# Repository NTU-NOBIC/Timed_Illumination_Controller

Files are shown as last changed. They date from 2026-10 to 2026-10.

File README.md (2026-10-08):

# Timed Illumination Controller

Firmware for an **Arduino Teensy 4.0** that coordinates two LED-control outputs with camera acquisition. In timed acquisition, the Teensy generates an external camera trigger and monitors the camera's trigger-ready feedback. A second mode uses camera feedback to control LED illumination during externally controlled continuous streaming.

## Features

- **Timed acquisition:** programmable camera trigger intervals (`t1`–`t4`) and LED lead/lag intervals (`t5`–`t8`).
- **Streaming mode:** LED control based on the camera feedback input and configurable `ts` interval.
- **Two active-HIGH channels:** Channel A and Channel B, with firmware-enforced mutual exclusion.
- **Camera monitoring:** frame-event counting from the camera feedback signal (mode-dependent validation).
- **Serial interface:** status, timing, acquisition, streaming, manual LED control, and configuration commands at **115200 baud**.
- **EEPROM presets:** save/load timing, cycle count, and selected channel in slots **0–10**; slot **0** is read at startup.

## Firmware and connections

Main sketch: [`Timed_Cam_Trig_LED_Control.ino`](Timed_Cam_Trig_LED_Control.ino)

| Teensy 4.0 pin | Firmware name | Direction | Purpose |
|---|---|---|---|
| 9 | `CAM_TRIG_OUT` | Output | Active-HIGH camera external trigger |
| 10 | `CAM_TRIG_READY` | Input (`INPUT_PULLUP`) | Camera feedback |
| 13 (`LED_BUILTIN`) | `GATE_A` | Output | Active-HIGH Channel A gate (also onboard LED) |
| 14 | `GATE_B` | Output | Active-HIGH Channel B gate |

**Important:** Confirm interface voltage levels, signal polarity, camera feedback configuration, and external LED driver requirements before connecting hardware. The sketch's naming of its camera and signals does not establish compatibility with every camera configuration.
Note: Teensy 4.0 GPIO input and output logic voltage is 3.3V.

## Quick start

1. Open `Timed_Cam_Trig_LED_Control.ino` in an Arduino environment configured for **Teensy 4.0**.
2. Compile and upload the sketch to the board.
3. Open a serial terminal at **115200 baud** and send commands terminated by a newline.
4. Send `help` to display the implemented commands or `?` to view status and timing settings.
5. For timed acquisition, configure the camera for the expected external-trigger/ready-signal operation, then issue `r`. Enter `q` followed by Enter to abort the timed run.
6. For streaming mode, ensure the camera feedback input is configured for the exposure signal expected by the firmware, then issue `stm on`; use `stm off` to disable the mode.

See [**USER_GUIDE.md**](./firmware/USER_GUIDE.md) under firmware folder for full commands, parameter definitions, default values, operating procedures, and EEPROM details.

## Documentation scope

This README describes functionality present in the supplied `.ino` sketch. Channel names A/B are firmware labels; the sketch does **not** assign LED colours or fluorescence filter bands. Camera operation and image saving must be verified separately on the actual system.

## Disclaimer and licensing

The firmware is provided without any assurance of suitability or safe operation with a particular hardware configuration. Review and test signal timing and electrical interfaces before use.

**License:** No license grant has been inferred from the `.ino` source. Add an appropriate `LICENSE` file only after confirming the intended licensing terms with the code's rights holders.

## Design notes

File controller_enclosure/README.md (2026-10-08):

# Controller Enclosure — 3D CAD Model

This folder contains a 3D CAD model for the enclosure associated with the **Timed Illumination Controller** project.

## File

| File | Description |
| --- | --- |
| [`Illum_driver_enclosure_v1b.step`](./Illum_driver_enclosure_v1b.step) | Controller enclosure geometry in STEP format (version `v1b`). |

## Viewing and Using the Model

1. Download `Illum_driver_enclosure_v1b.step`.
2. Open or import it in a CAD application that supports STEP files (for example, FreeCAD, Autodesk Fusion, or SOLIDWORKS).
3. Inspect the geometry, dimensions, clearances, and fit against your hardware before manufacturing.
4. If required, export the model to a manufacturing format such as STL for 3D-printing preparation.

## File Information

- **Format:** STEP (`.step`), a neutral 3D CAD exchange format.
- **STEP schema:** AP214 (`AUTOMOTIVE_DESIGN`).
- **Model geometry:** The uploaded file contains two named solid bodies, `Body1` and `Body3`.
- **Version:** `v1b` (from the filename).

> **Note:** Material, print orientation, manufacturing tolerances, hardware compatibility, and assembly instructions are not specified in the STEP file. Verify these before fabrication.

## Related Project Files

See the [main project README](../README.md) for an overview of the Timed Illumination Controller.

## Disclaimer

The CAD model is provided **AS IS**, without a guarantee of fitness for a particular application. Check dimensions, electrical clearances, and mechanical fit before fabrication or use.

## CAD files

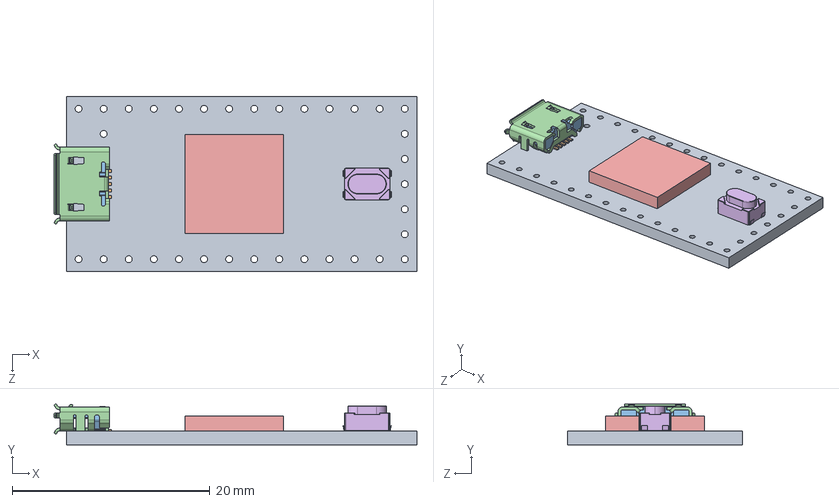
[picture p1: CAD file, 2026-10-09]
PCB/3d/Teensy_4.0_Assembly.STEP
36.8 x 4.12 x 17.7 mm
Teensy_4.0_PCB
Micro USB-B Female 5Pin SMD
NXP iMXRT1062
SKRPACE010 v4

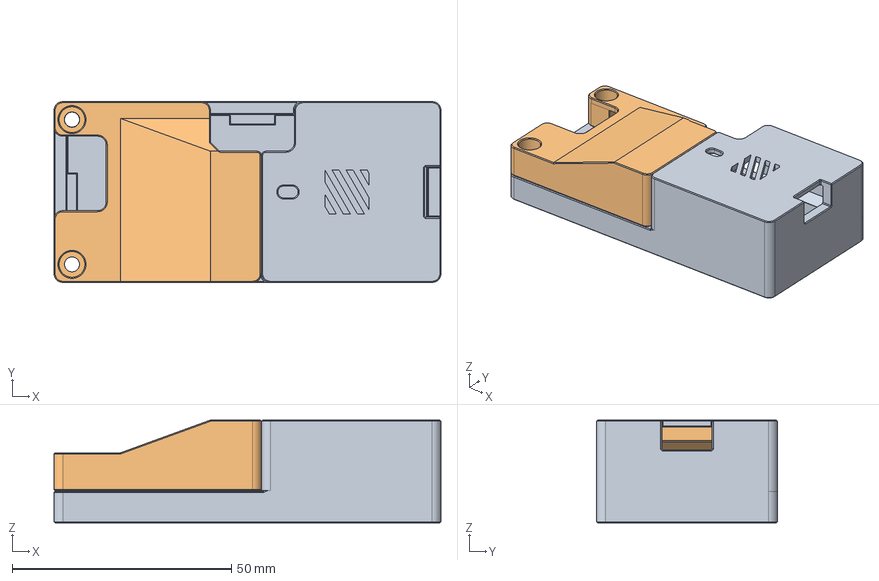
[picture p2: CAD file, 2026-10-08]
controller_enclosure/Illum_driver_enclosure_v1b.step
88.2 x 41.2 x 23.4 mm

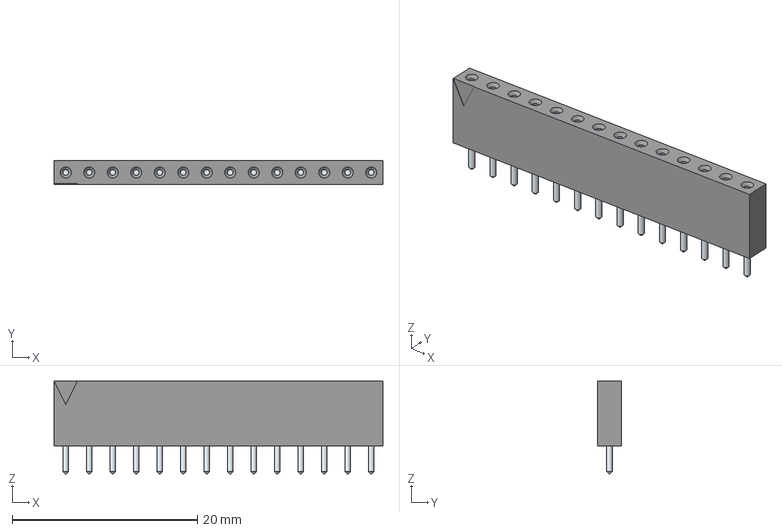
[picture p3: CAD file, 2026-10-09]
PCB/3d/801-87-014-10-001101.stp
35.6 x 2.54 x 10.0 mm
LeadsArray

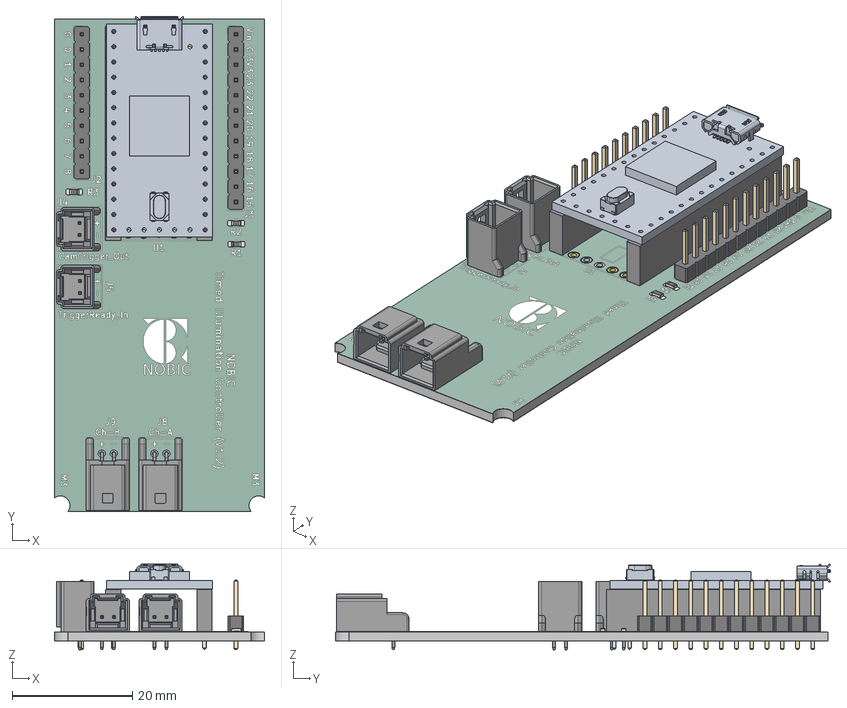
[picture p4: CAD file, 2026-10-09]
PCB/3d/IlluminationDriver_v1p2.step
35.0 x 82.4 x 14.3 mm
R_0603_1608Metric x 3
DF51KB-2P-2DS x 2
PinHeader_1x10_P2.54mm_Vertical
DF51K-2P-2DSA x 2
LeadsArray x 2
Teensy_4.0_PCB
Micro USB-B Female 5Pin SMD
NXP iMXRT1062
SKRPACE010 v4
PinHeader_1x12_P2.54mm_Vertical
IlluminationDriver_copper
IlluminationDriver_pad
IlluminationDriver_via
IlluminationDriver_silkscreen
IlluminationDriver_soldermask
IlluminationDriver_PCB

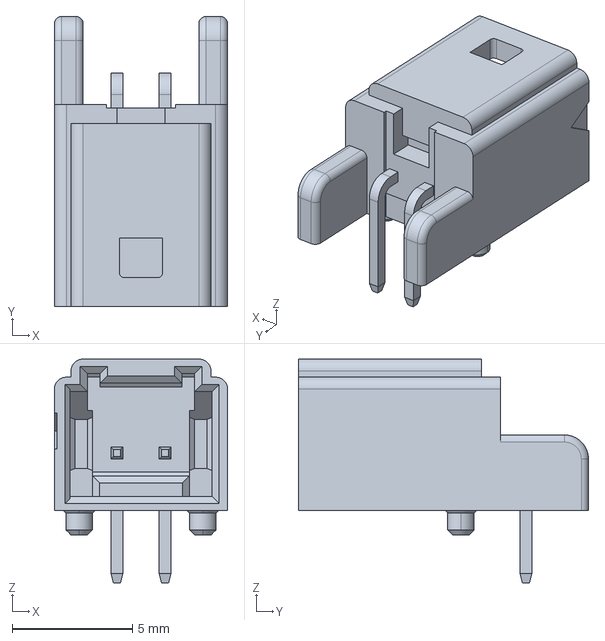
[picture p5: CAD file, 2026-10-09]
PCB/3d/DF51KB-2P-2DS(800).stp
7.20 x 12.0 x 9.30 mm

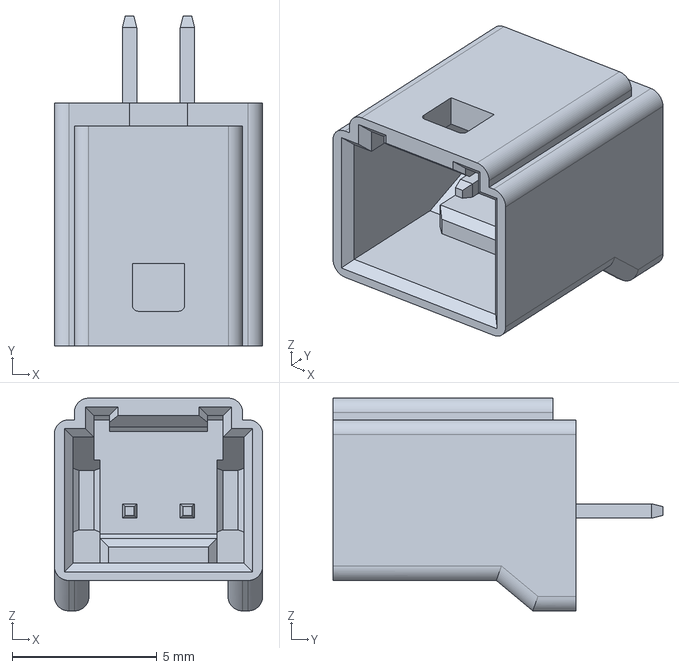
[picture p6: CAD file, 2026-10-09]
PCB/3d/DF51K-2P-2DSA(800).stp
7.20 x 11.4 x 7.35 mm

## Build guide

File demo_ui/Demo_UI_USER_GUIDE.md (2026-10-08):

# Demo UI User Guide

This guide explains how to install and use the Python demo UI for the Timed Illumination Controller. The UI provides serial control of the Teensy running `Timed_Cam_Trig_LED_Control.ino`.

## Recommended GitHub layout

Use the folder name `demo_ui` because it is short, descriptive, and follows common lowercase repository naming conventions.

```text
Timed_Illumination_Controller/
|-- README.md
|-- firmware/
|   |-- USER_GUIDE.md
|   `-- Timed_Cam_Trig_LED_Control.ino
`-- demo_ui/
    |-- Demo_UI_USER_GUIDE.md
    |-- Time_Illumination_GUI.py
    |-- requirements.txt
    `-- Connection_MM_setup.pdf
```

### Files to upload

- `Demo_UI_USER_GUIDE.md` - installation and operating instructions for the demo UI.
- `Time_Illumination_GUI.py` - the main Python/Tkinter application.
- `requirements.txt` - Python package dependency list. The current application requires `pyserial>=3.5,<4`.
- `Connection_MM_setup.pdf` - connection and Micro-Manager setup instructions opened by the UI's **Connection & Micro-Manager Setup** button.

## Requirements

- Windows computer (the UI uses Windows to open the bundled setup PDF).
- Python 3.10 or later recommended.
- Tkinter, normally included with the standard Windows Python installer.
- A Teensy programmed with `firmware/Timed_Cam_Trig_LED_Control.ino`.
- A USB data cable.
- Micro-Manager and the microscope hardware configuration described in `Connection_MM_setup.pdf`, when camera acquisition is required.

## Install from source

Open PowerShell in the repository root and run:

```powershell
cd demo_ui
py -m pip install --upgrade pip
py -m pip install -r requirements.txt
```

## Start the UI

```powershell
py Time_Illumination_GUI.py
```

## Connect to the controller

1. Upload the firmware to the Teensy and connect it to the computer by USB.
2. Close Arduino Serial Monitor and any other application using the Teensy's serial port.
3. Start the demo UI.
4. Select the Teensy's **COM port**. Use the refresh button if the port does not appear.
5. Click **Connect**. The UI connects at 115200 baud and reads the controller's current settings.
6. Confirm that the status reports `Connected to COM...` and that received messages appear in the serial log.

If more than one COM port is shown, disconnect and reconnect the Teensy and note which port disappears and returns.

## Main controls

### Timing settings

- `t1` to `t4` define the primary camera/illumination timing sequence in milliseconds.
- `t5` to `t8` define the alternating LED-channel timing sequence in milliseconds.
- `ts` is the expected Micro-Manager exposure time. It must be an integer of at least 10 ms.
- **Total Cycle** sets the controller cycle count. Accepted values are 0 through 2,147,483,647.

Edit a value and click the corresponding **Set** button, or press Enter in the field. A value is treated as applied only after the controller confirms it. Refer to the timing diagram in the UI and the firmware guide for the exact meaning of each interval.

### Illumination and operating mode

- **Illumination ON/OFF** manually controls illumination.
- **LED Channel A/B** selects an illumination channel.
- **Time Illumination** runs the programmed timed sequence.
- **Continuous Streaming** coordinates illumination with continuous camera streaming. Set `ts` to match the Micro-Manager camera exposure.
- **Start** begins a test run using the current controller settings; while a run is active, the same button stops it.

### Timing presets

The controller provides EEPROM preset slots `#0` through `#10`.

- **Save** overwrites the selected slot after confirmation.
- **Read** loads the selected slot and refreshes the displayed settings.
- Preset `#0` is the controller's power-on default.

Saving writes to the controller's non-volatile memory. Verify all timing values before overwriting a preset.

### Serial logger and command prompt

- **Help** requests the firmware command list.
- **Refresh Status** requests the current controller state.
- **Manual Command** sends a firmware serial command directly.
- **Clear Log** clears only the on-screen log; it does not change controller settings.

## Suggested demo procedure

1. Connect the Teensy and confirm the current values populate the UI.
2. Load a known EEPROM preset.
3. Select LED Channel A or B and briefly test **Illumination ON/OFF**.
4. Select the required operating mode.
5. Verify `t1` through `t8`, `ts`, and **Total Cycle** against the experiment plan.
6. For Micro-Manager acquisition, open **Connection & Micro-Manager Setup**, complete the hardware configuration, and set the camera exposure to the same value as `ts`.
7. Click **Start** and watch the status and serial log for controller errors.
8. Click **Stop** before disconnecting or changing hardware.

## Troubleshooting

### No COM port appears

- Confirm that the USB cable supports data, not charging only.
- Install the appropriate Teensy/USB driver if Windows does not recognize the board.
- Click refresh after reconnecting the controller.
- Check Windows Device Manager for the assigned COM port.

### Connection fails or the port is busy

- Close Arduino Serial Monitor, another copy of the demo UI, and other serial tools.
- Disconnect and reconnect the Teensy, refresh the list, and try again.
- Confirm that the firmware is running and uses 115200 baud.

### `PySerial is required`

Run this command using the same Python interpreter that starts the UI:

```powershell
python -m pip install -r requirements.txt
```

### The setup PDF does not open

Keep `Connection_MM_setup.pdf` in the `demo_ui` directory beside `Time_Illumination_GUI.py`. The UI locates the PDF relative to the Python script or packaged executable.

### Values do not update

- Check the serial log for `Error` or `Invalid` responses.
- Ensure values are non-negative integers; `ts` must be at least 10 ms.
- Use **Refresh Status** to read the controller state again.
- Confirm that the firmware version matches the UI's serial command protocol.

## Safety and shutdown

Before connecting illumination hardware, verify the driver voltage, current limit, channel wiring, and active logic levels. Use conservative timing values for the first test. Stop the sequence, turn illumination off, disconnect the UI, and then power down the external hardware.

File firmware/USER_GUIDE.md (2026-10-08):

# Timed Illumination Controller — User Guide

This guide documents the behaviour implemented in [`Timed_Cam_Trig_LED_Control.ino`](Timed_Cam_Trig_LED_Control.ino).

## 1. System overview

The **Teensy 4.0** controls two active-HIGH outputs (`GATE_A`, `GATE_B`) and uses a camera feedback input (`CAM_TRIG_READY`). Its own external-trigger output (`CAM_TRIG_OUT`) is used in **timed acquisition**. In **continuous streaming**, camera acquisition is controlled externally and the feedback input is treated as an exposure-activity signal.

The main loop writes the gate outputs so **only the selected channel can be HIGH**. The `gateA_on()` and `gateB_on()` functions also force the opposite gate LOW before turning on their selected gate.

## 2. Hardware signals

| Symbol | Teensy pin | Configuration | Code-defined function |
|---|---:|---|---|
| `CAM_TRIG_OUT` | 9 | Digital output, initially LOW | Active-HIGH signal to camera EXT TRIGGER input |
| `CAM_TRIG_READY` | 10 | `INPUT_PULLUP` | Trigger-ready feedback in timed mode; exposure feedback in streaming mode |
| `GATE_A` | 13 (`LED_BUILTIN`) | Digital output, initially LOW | Active-HIGH Channel A gate |
| `GATE_B` | 14 | Digital output, initially LOW | Active-HIGH Channel B gate |

**Electrical check:** Ensure the connected camera input/output and LED-driver interfaces are electrically compatible with Teensy 4.0 GPIO. Pin 13 also controls the onboard LED. The code does not define an external electrical schematic or a specific LED-driver circuit.

## 3. Serial connection

The code calls `Serial.begin(115200)`. Open a serial monitor at **115200 baud** and send each command as a line (newline-terminated). The exact available commands can also be listed using `help`.

### Command reference

| Command | Firmware action |
|---|---|
| `help` | Show command help |
| `?` | Show current status and timing settings |
| `ch?` | Show selected channel |
| `on?` or `off?` | Show Channel A / Channel B status |
| `A` | Select Channel A and deselect Channel B |
| `B` | Select Channel B and deselect Channel A |
| `on` | Enable LED output for currently selected channel |
| `off` | Disable LED output for currently selected channel |
| `t?` | Show current timing settings |
| `t a/b/c/d` | Set `t1/t2/t3/t4` in milliseconds |
| `p a/b/c/d` | Set `t5/t6/t7/t8` in milliseconds |
| `c?` | Display configured total cycles |
| `c N` | Set total acquisition cycles |
| `r` | Start timed exposure/LED acquisition |
| `q` | Abort a running timed acquisition when prompted (follow with Enter) |
| `stm?` | Show streaming mode status |
| `stm on` | Enable continuous streaming LED response |
| `stm off` | Disable continuous streaming mode and clear LED enables |
| `ts?` | Display `ts` in milliseconds |
| `ts N` | Set `ts` in milliseconds (requires at least 10 ms) |
| `s N` | Save configuration to EEPROM slot `N`, from 0 through 10 |
| `l N` | Load configuration from EEPROM slot `N`, from 0 through 10 |

Examples:

```text
help
?
A
on
off
t 10/15/40/100
p 0/0/0/0
c 100
r
```

Do not send commands intended for the normal command parser while a timed acquisition is running; the timed routine separately checks serial input for `q` to abort.

## 4. Timing model

The firmware stores timing in **microseconds** (`unsigned long`), while serial `t`, `p`, and `ts` values are entered in **milliseconds**.

### Compiled initial values

| Parameter | Initial value | Meaning |
|---|---:|---|
| `t1` | 10 ms | Channel A camera trigger HIGH interval |
| `t2` | 15 ms | Following interval after `t1` |
| `t3` | 40 ms | Channel B camera trigger HIGH interval |
| `t4` | 100 ms | Following interval after `t3` |
| `t5` | 15 µs | Channel A LED pre-trigger interval (displayed as 0 ms) |
| `t6` | 0 ms | Channel A LED post-trigger interval |
| `t7` | 15 µs | Channel B LED pre-trigger interval (displayed as 0 ms) |
| `t8` | 0 ms | Channel B LED post-trigger interval |
| `ts` | 10 ms | Streaming exposure timing setting |
| `cycle_Total` | 1000 | Number of requested timed cycles |

**Startup note:** `setup()` loads **EEPROM slot 0** after initialization, so stored settings can replace these compiled values. Do not assume the values above are active without checking `?` or `t?`.

The firmware displays these timing relationships:

```text
Cycle duration = t1 + t2 + t3 + t4
Channel A LED ON time = t5 + t1 + t6
Channel B LED ON time = t7 + t3 + t8
```

For two-channel timing, it calculates the waits as `t_wait1 = t2 - t6 - t7` and `t_wait2 = t4 - t8 - t5`. There are alternate wait expressions when `t1` or `t3` is zero, in which case the corresponding channel is skipped. Timing-setting commands validate some relationships between these parameters.

A zero-millisecond request for `t5` or `t7` is represented internally as **15 µs** when the corresponding channel's exposure interval is active, to accommodate MCU response time. Consult `t?` for how the sketch reports its current settings.

## 5. Timed acquisition (`r`)

In this mode the Teensy drives `CAM_TRIG_OUT` and monitors `CAM_TRIG_READY` as the camera's trigger-ready signal.

1. Configure the camera to respond to the external trigger and provide the trigger-ready feedback expected by the firmware.
2. Check the current timing settings using `t?`; adjust with `t ...`, `p ...`, and `c N` as needed.
3. Send `r` to run the requested cycles.
4. The firmware first waits for `CAM_TRIG_READY` to be HIGH, aborting after **15 seconds** if that condition does not occur.
5. During each cycle, a nonzero `t1` enables the Channel A trigger segment; a nonzero `t3` enables the Channel B trigger segment. The appropriate LED gate is switched according to the configured pre-/post-trigger timing.
6. Enter `q` followed by Enter to abort during the run, where the routine checks serial input.

### Feedback-based frame count

The timed-mode interrupt first captures a **falling edge** on `CAM_TRIG_READY`, then measures the LOW pulse until the **rising edge**. The frame counter increments only when the pulse duration lies within the mode's channel-specific bounds:

```text
Channel A: t1 <= pulse duration <= t1 + 17,000 µs
Channel B: t3 <= pulse duration <= t3 + 17,000 µs
```

These bounds come from `TRIG_RDY_AFTER_EXPO` (15,000 µs) plus a further 2,000 µs allowance. An out-of-range pulse produces an alert. **The count indicates accepted feedback pulses; it does not verify that image data were successfully saved.**

A full cycle can issue up to **two exposure triggers** (one for each channel), or one if one of the corresponding exposure intervals is zero. The sketch displays an expected image count derived from the cycle count and the enabled intervals.

## 6. Continuous streaming (`stm on`, `stm off`)

In streaming mode, the code describes the camera as using **internal triggering** with its output configured for **EXPOSURE** activity. Acquisition is controlled by the camera / Micro-Manager, not by the Teensy's timed `CAM_TRIG_OUT` sequence.

1. Select the required channel with `A` or `B`.
2. Configure a matching exposure time with `ts N` (minimum **10 ms**).
3. Configure the camera feedback interface as required by this mode.
4. Send `stm on` to arm the feedback interrupt.
5. The streaming interrupt increments `frameNo` on each detected **falling edge** and enables the selected channel.
6. The main loop refreshes a timer for **`ts + 100,000 µs`** after a detected falling edge. When the timer expires, the channel is disabled and a frame total is printed; the firmware subtracts one from the counted edges in that timeout handler.
7. Send `stm off` to disable the streaming interrupt and LED enables.

**Code-specific distinction:** streaming mode does **not** perform the timed mode's falling-to-rising pulse-width validation. Its edge count is not equivalent to confirmed saved camera frames. The comment near the streaming code mentions another timer allowance, but the executable `cam_ExpoTimer.begin(...)` call uses `ts + 100000` µs; that executable value is documented here.

## 7. Manual channel operation

Use `A` or `B` to select the channel, then `on` or `off` to control the selected LED:

```text
A
on
on?
off
B
on
on?
off
```

Only one gate is intended to be active at a time. `GATE_A` is also the Teensy's onboard LED pin.

## 8. EEPROM presets

The sketch reads and writes preset slots **0 through 10**. Each slot uses a 100-byte address stride (`address = slot * 100`). The stored data are:

- `t1`–`t8`
- `ts`
- `cycle_Total`
- selected channel (`ch`)

Use `s 0` to save the currently active configuration as the setting loaded at boot. Use `s 5` and `l 5`, for example, to save and recall a separate configuration.

```text
s 0
s 5
l 5
?
```

The code does not implement a preset name or signature, nor an explicit validity check before using values read from EEPROM. After first programming or changing hardware, inspect current settings before running acquisition.

## 9. Implementation cautions

- **Camera signals:** timed mode expects trigger-ready behaviour, whereas streaming mode expects exposure activity on the same input. Configure the camera for the mode being used.
- **Signal compatibility:** verify voltage, polarity and source/sink limits of every connected interface. The firmware itself supplies no verified wiring diagram or isolation circuit.
- **Serial responsiveness:** `r` executes a blocking acquisition routine; normal command handling resumes after it finishes or aborts.
- **Timing limitations:** software execution, interrupt latency, camera behaviour and peripheral response can affect actual timing. Validate waveforms before production use.
- **Frame accounting:** reported frames are based on camera signal events, not independently verified captured/saved image files.
- **Optical assignment:** the source labels only Channel A and Channel B. It does not identify LED colours, filters or fluorophores.
- **License:** this `.ino` source does not establish license terms. Do not assume a particular software license solely from this guide.

## 10. Source of truth

If documentation and behaviour disagree, inspect the exact version of [`Timed_Cam_Trig_LED_Control.ino`](Timed_Cam_Trig_LED_Control.ino) deployed on the Teensy. This guide reflects the supplied sketch rather than a separately verified hardware test.

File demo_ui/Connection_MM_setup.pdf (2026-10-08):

# 1. Electronic Hardware Connections

The following electronic hardware’s are main components of Tilting Microscope.
- | Camera | : Hamamatsu ORCA-Flash4.0 V3 C13440-20CU
- PCB Module : “Illumination + Sync” Board (with on-board Arduino Teensy 4.0 MCU)

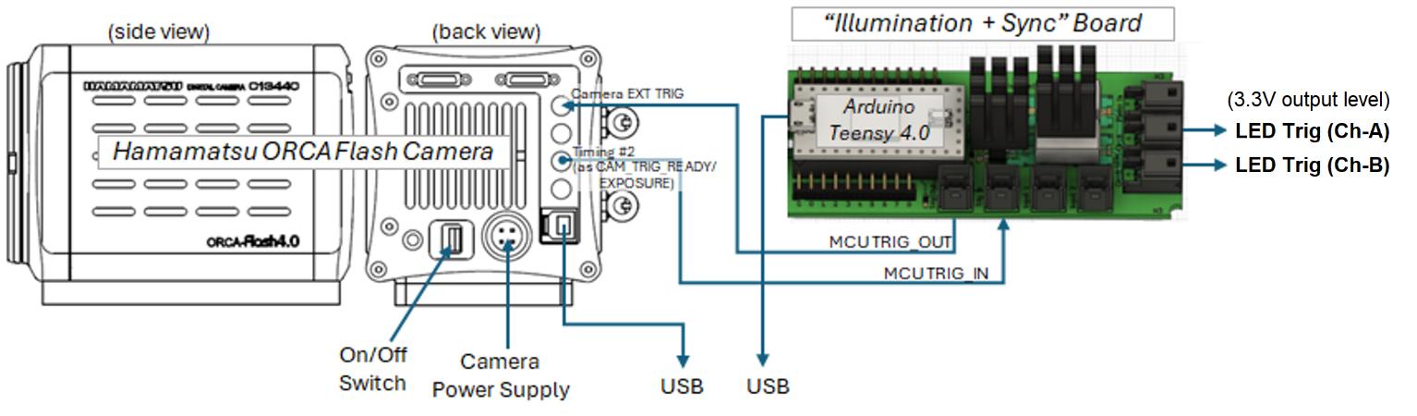
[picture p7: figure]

# 2. Camera

sCMOS camera used for Tilting Microscope
- | Camera Model | : Hamamatsu ORCA-Flash4.0 V3 C13440-20CU
- Data/Control Interface: USB, 3.3V I/O; EXT TRIG and Timing #2 (as TRIG_READY and EXPOSURE)
- | URL | : https://www.hamamatsu.com/jp/en/product/cameras/cmos-cameras/C13440-20CU.html

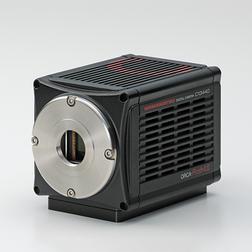
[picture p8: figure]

Hamamatsu ORCA-Flash4.0 Camera
Main specifications:
- 2048 x 2048 pixels
- 8-bit, 12-bit, 16-bit monochrome image format (12-bit is not supported by Micro-Manager driver)
- 1x1, 2x2 and 4x4 binning
- External Trigger and Internal Trigger
- USB 3.0 interface for control and image data transfer

# 3. Micro-Manager

Micro-Manager is used to configure camera settings, including exposure, the total number of image frames, image format, and binning. It also manages saving image frames into a stacked TIFF file format.

Additionally, it configures the camera to properly interact with an external "Illumination Driver + Sync" board to run continuous streaming mode and timed illuminations mode for image acquisition.

Download Link: https://download.micro-manager.org/nightly/2.0/Windows/
(Time_Illumination.exe control interface was tested with “MMSetup_64bit_2.0.3_20230905.exe”)

## 3.1 Micro-Manager Configuration for Hamamatsu Camera

Steps to create new configure Micro-Manager for Tilting Microscope:
1. Power on Hamamatsu camera and connect it to computer USB interface
2. Launch Micro-Manager
3. When prompt for Hardware Configuration File
- for the first time, select “(none)”
- for subsequent launch, just load the desired configuration file and skip all the following steps.
4. Under Micro-Manager Menu, select “Devices | Hardware Configuration Wizard…”
5. Select “Create new configuration”, “Next”
6. Under Available Devices, look for HamamatsuHam,
- Select “HamamatsuHam_DCAM: Universal adapter using Hamamatsu DCAM interface”
- “Add…”. Put the cursor in Device name box and press enter.
(Do wait for a while Micro-Manager to detect the camera.)
7. Select the detected camera (with status “OK”), “Next”
8. “Next”, “Next”, “Next”
9. “Browse”, select folder and enter the name of the configuration file
(eg “C:\Program Files\Micro-Manager-2.0\Timed_Illumination_Hamamatsu_01.cfg”)
10. “Finish”
Creation of Grouping (Binning, pixel depth, for Continuous Streaming Mode/Timed Illuminations Mode)
11. Configuration settings, “Group:”, “+”:
- Group name, enter “Bit Depth of Pixel”
- Tick the checkbox “HamamatsuHam_DCM-PixelType”
- “OK”

12. Configuration settings, “Group:”, “+”:
- Group name, enter “Camera Operation Mode”
- Tick the checkboxes
“HamamatsuHam_DCAM-OUTPUT TRIGGER KIND[1]” “HamamatsuHam_DCAM-OUTPUT TRIGGER POLARITY[1]” “HamamatsuHam_DCAM-OUTPUT TRIGGER SOURCE[1]” “HamamatsuHam_DCAM-TRIGGER ACTIVE” “HamamatsuHam_DCAM-TRIGGER SOURCE”
“HamamatsuHam_DCAM-Trigger”
“HamamatsuHam_DCAM-TriggerPolarity”
- Preset Name : “Continuous Streaming”; (settings are related to I/O interface with external circuit)
- Select the Preset Value as below.

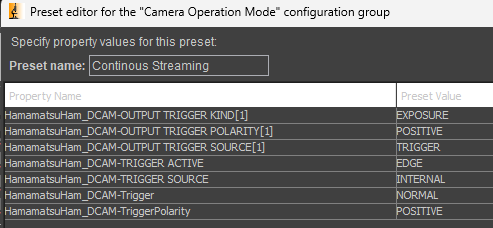
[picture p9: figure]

- “OK”
13. Create another preset name:
- Highlight “Camera Operation Mode”
- Preset: “+”
- Preset Name: “Timed Illumination”; (settings are related to I/O interface with external circuit)
- Select the Preset Value as below:

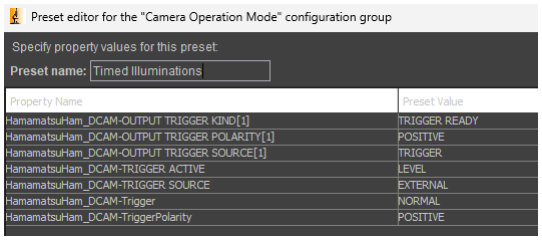
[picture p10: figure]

- “OK’
14. “Save” to save the configuration to the same name
(e.g. “C:\Program Files\Micro-Manager-2.0\Timed_Illumination_Hamamatsu_01.cfg”)

Note:
Edit the configuration file directly with text
editor to disable the 12-bit pixel depth by
deleting the 12-bit setting lines, as the Micro-Manager 2.0.0 driver is not supporting well 12-bit pixel depth.
(Micro-Manager Menu: “Devices”/”Load Hardware Configuration” to load the new configuration file for the changes to take effect.)

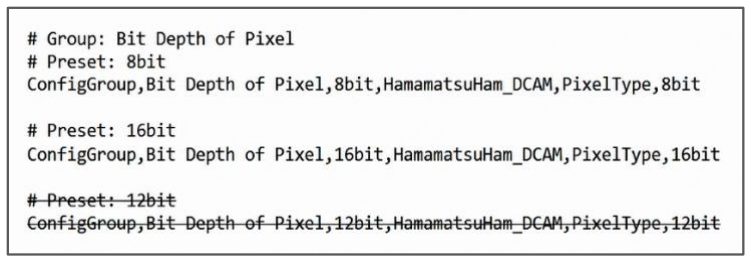
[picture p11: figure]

## 3.2 Micro-Manager Sequencer Buffer Memory

You may encounter "sequence buffer overflow" (also known as "circular buffer overflow") errors during acquisitions, particularly at high frame rates. To mitigate this, consider increasing the sequence buffer size for fast streaming of large images. Alternatively run the camera at lower pixel depth (8-bit instead of 16-bit) or use binning (2x2 or 4x4 instead of 1x1) to reduce the image size when running fast streaming.

The sequence buffer temporarily stores newly acquired images until the Micro-Manager application is ready to process them (display, save, etc.). It helps manage occasional glitches that slow down software processing, ensuring the camera can maintain its set rate of image acquisition. Note that the sequence buffer is not used for Snap acquisitions or Multi-Dimensional Acquisitions with sufficient time between frames.

You can adjust the Sequence Buffer Size setting under the Micro-Manager menu (Tools | Options…).

As a general guideline, set the buffer size to 20-100 times the size of a single image from your camera. The buffer should be large enough to accommodate its intended use but small enough to leave RAM available for other tasks and the Operating System.

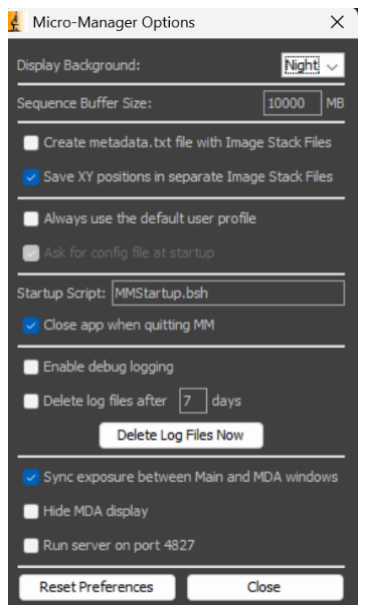
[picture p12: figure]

Be aware that if the sequence buffer size exceeds the available physical RAM
+ virtual memory, Windows OS will try to increase the virtual memory using
more hard disk space. This can significantly increase the launch time of Micro-Manager (potentially one minute or longer). When setting a very large buffer size (e.g., 70000 MB), be patient as Micro-Manager may appear unresponsive during this virtual memory creation. You can monitor memory usage via the Windows Task Manager.

Refer the link below for details. https://micro-manager.org/Micro-Manager_Configuration_Guide#memory-settings.

## 3.3 Image Size

The following table gives good estimation of the image size created under different pixel depth and binning settings. One would multiple the image size with the total number of frames to get a good estimate of the file size created. (12-bit pixel depth is not used, as not supported by Micro-Manager 2.0.0 driver.)

Camera pixel size is 2048 x 2048
# | Pixel Depth | Binning | Image Size

1 | 16-bit | 1x1 | 2048 x 2048 x 2-byte (16-bit) = 8.39 MByte
2 | 16-bit | 2x2 | 1024 x 1024 x 2-byte (16-bit) = 2.10 MByte
3 | 16-bit | 4x4 | 512 x 512 x 2-byte (16-bit) = 0.524 MByte
4 | 8-bit | 1x1 | 2048 x 2048 x 1-byte (8-bit) = 4.19 MByte
5 | 8-bit | 2x2 | 1024 x 1024 x 1-byte (8-bit) = 1.05 MByte
6 | 8-bit | 4x4 | 512 x 512 x 1-byte (8-bit) = 0.264 MByte

## 3.4 Live Preview (through Micro-Manager interface)

To preview the camera image:
Under Micro-Manager
- configure the “Camera Operating Mode” to “Continuous Streaming”
- Select the desired “Binning” and “Bit Depth of Pixel” settings
- Press “Live” to preview the image.
(refer commands on CoolTerm for LED illumination control)

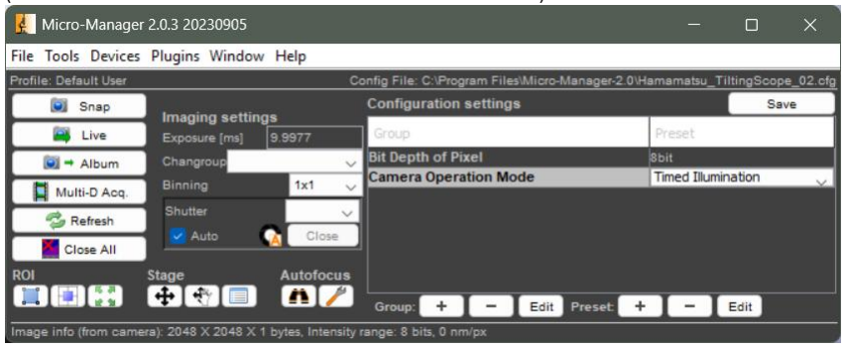
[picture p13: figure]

Under Time_Illumination terminal software
- Connect using the corresponding COM port.
- Set the mode to “Continuous Streaming”
- Set the desired LED illumination channel (one channel at a time)
- Set the ts timing to tally with Micro-Manager Exposure setting, round up to nearest ms.

The LED illumination will then automatically turn on and off according to camera exposure, and Live/”Stop Live” operation

## 3.5 Multi-Dimensional Acquisition with Micro-Manager

Multi-Dimensional Acquisition in Micro-Manager is a powerful feature that allows users to capture complex datasets by varying multiple parameters across different dimensions.
For Tilting Microscope application, configure the following:
- Select “Time Points” checkbox
- Count : set Total No of Frames to capture
- Save Images (refer below for example illustration)
- “Directory root”
- “Name prefix”
- “Saving format”

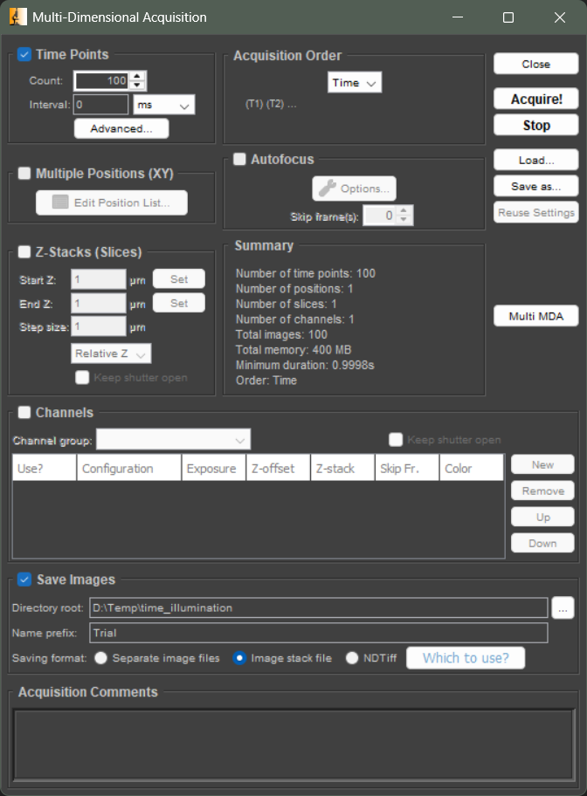
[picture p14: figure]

To start the acquisition
- Micro-Manager
- | “Count” | : 200 (as example)
- Run command : “Acquire!” button
- Timed_Illumination.exe terminal application
- Connect to the MCU board using the corresponding COM port
- Set “Total Cycle” corresponding to half value of Micro-Manager “Count”
- Set Mode to “Time Illumination”
- Press “Start” button

## 3.6 ROI (Region Of Interest) Operation on Micro-Manager

Follow steps below under Micro-Manager to set the camera to define and acquire images within a region of interest (ROI) .

Enable and Define ROI
1. Set “Camera Operating Mode” to “Continuous Streaming”
2. Press | to select the whole region
3. Press | to take a snap shot of whole region
4. Draw a rectangle over the image to define the desired ROI
5. Press | to enable the ROI mode
6. Press | to take a snap shot of the ROI

Subsequent camera operations will only acquire images within the ROI.

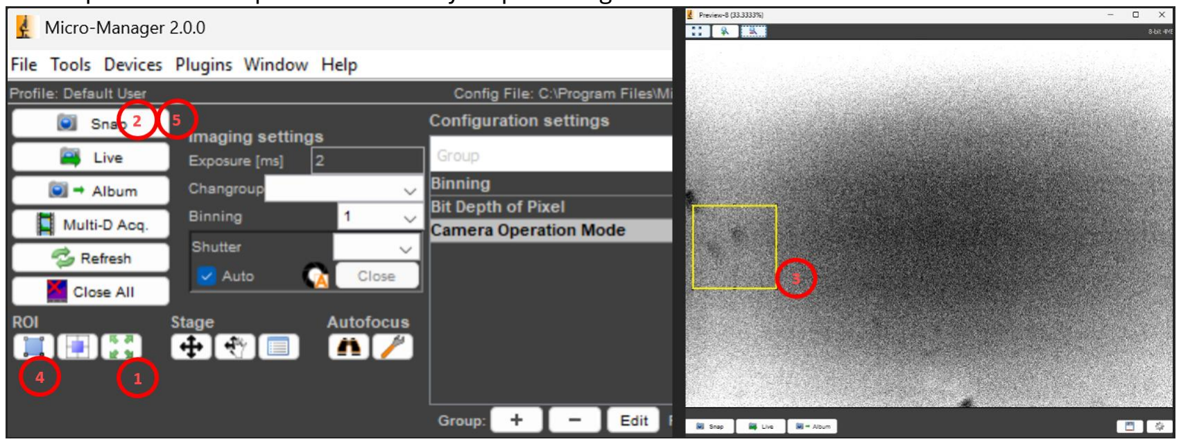
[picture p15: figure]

Disable ROI and revert back to full region
1. Press | to select the whole region
2. Press | to take a snap shot of whole region

Subsequent camera operations will acquire images of the whole region.

# 4. Manual LED illumination operation

For manual LED On/Off operation
- Connect using the corresponding COM port.
- Use these buttons to operate the LED illumination manually

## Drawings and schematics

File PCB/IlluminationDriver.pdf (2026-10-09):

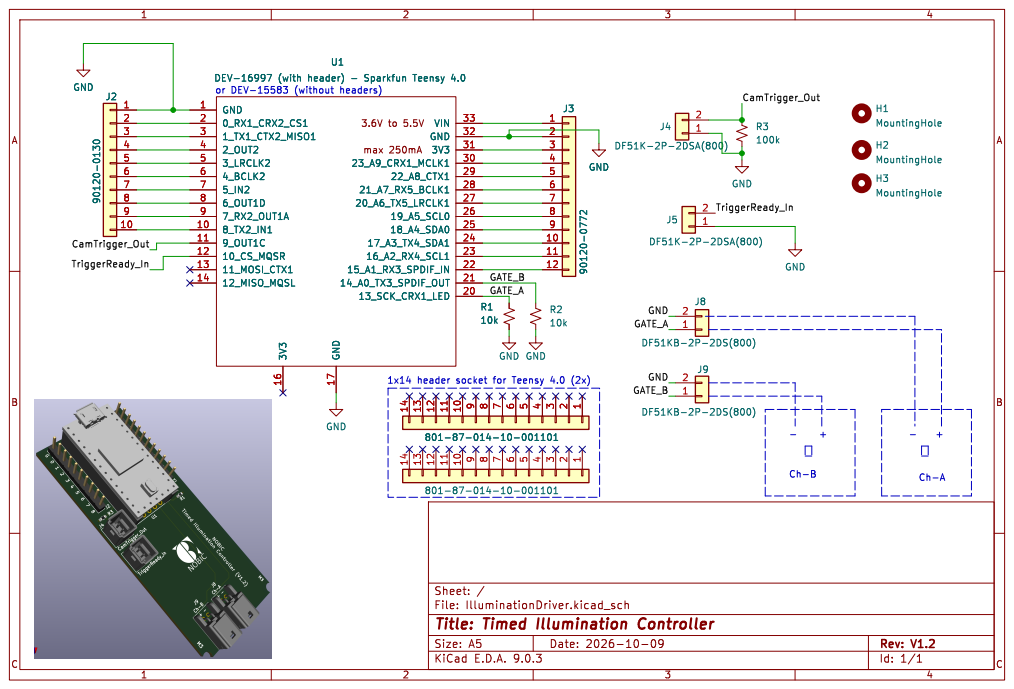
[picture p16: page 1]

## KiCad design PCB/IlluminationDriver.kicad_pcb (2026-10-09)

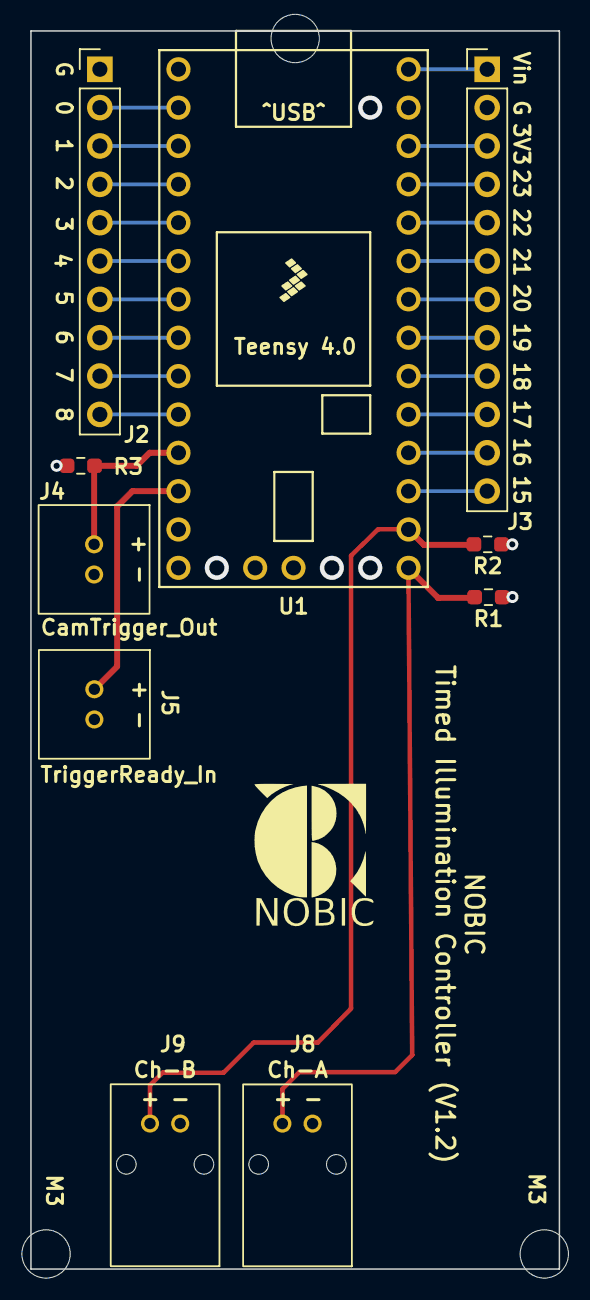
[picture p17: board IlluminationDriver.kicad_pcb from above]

Board: 2 copper layers, 35.0 x 82.0 mm, 13 parts (0 on the bottom side), 25 nets.

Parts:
H1, H2, H3: MountingHole; MountingHole_3.2mm_M3_DIN965
J2: 801-87-010-10-001101; PinHeader_1x10_P2.54mm_Vertical
J3: 801-87-012-10-001101; PinHeader_1x12_P2.54mm_Vertical
J4, J5: DF51K-2P-2DSA(800); DF51K-2P-2DSA
J8, J9: DF51KB-2P-2DS(800); DF51K-2P-2DS
R1, R2: 10k; R_0603_1608Metric_Pad0.98x0.95mm_HandSolder
R3: 100k; R_0603_1608Metric_Pad0.98x0.95mm_HandSolder
U1: DEV-15583 (Sparkfun Teensy 4.0); Teensy4p0_NoSMTs_Redux

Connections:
/CamTrigger_Out: J4.2, R3.2, U1.11 (9_OUT1C)
/GATE_A: J8.1, R1.2, U1.20 (13_SCK_CRX1_LED)
/GATE_B: J9.1, R2.2, U1.21 (14_A0_TX3_SPDIF_OUT)
/TriggerReady_In: J5.2, U1.12 (10_CS_MQSR)
GND: J2.1, J3.2, J4.1, J5.1, J8.2, J9.2, R1.1, R2.1, R3.1, U1.1 (GND), U1.17 (GND), U1.32 (GND)
unnamed: J2.2, U1.2 (0_RX1_CRX2_CS1)
unnamed: J2.3, U1.3 (1_TX1_CTX2_MISO1)
unnamed: J2.4, U1.4 (2_OUT2)
unnamed: J2.5, U1.5 (3_LRCLK2)
unnamed: J2.6, U1.6 (4_BCLK2)
unnamed: J2.7, U1.7 (5_IN2)
unnamed: J2.8, U1.8 (6_OUT1D)
unnamed: J2.9, U1.9 (7_RX2_OUT1A)
unnamed: J2.10, U1.10 (8_TX2_IN1)
unnamed: J3.1, U1.33 (VIN)
unnamed: J3.3, U1.31 (3V3)
unnamed: J3.4, U1.30 (23_A9_CRX1_MCLK1)
unnamed: J3.5, U1.29 (22_A8_CTX1)
unnamed: J3.6, U1.28 (21_A7_RX5_BCLK1)
unnamed: J3.7, U1.27 (20_A6_TX5_LRCLK1)
unnamed: J3.8, U1.26 (19_A5_SCL0)
unnamed: J3.9, U1.25 (18_A4_SDA0)
unnamed: J3.10, U1.24 (17_A3_TX4_SDA1)
unnamed: J3.11, U1.23 (16_A2_RX4_SCL1)
unnamed: J3.12, U1.22 (15_A1_RX3_SPDIF_IN)

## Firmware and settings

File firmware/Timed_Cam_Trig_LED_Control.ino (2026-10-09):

/*
Timed Illumination Controller
Arduino Teensy 4.0 MCU as master to drive TRIGGER OUT signal to Hamamatsu ORCHA Flash Camera EXT TRIGGER input to control the camera exposure in sync with two LED control outputs.
  - Ch-A (active HIGH)
  - Ch-B (active HIGH)
  - only one channel active at a time. (Not possible to turn on both channel at the same time)
  - MCU detects if camera is responding to TRIGGER_OUT signal by monitoring TRIGGER READY signal (CAM_TRIG_READY) from Camera
  - A frame count is incremented when a valid CAM_TRIG_READY is detected
  - t1-t8 and ts timing, total cycle no, and active channel can be saved into EEPROM
  - ch-A and ch-B can be manually turned-on and off, one at a time.
  - UART Baudrate: 115200
*/

#include <IntervalTimer.h>
#include <EEPROM.h>

#define DEVICE_NAME "SCELSE/NOBIC - Timed Illumination Controller, ver 1.0.0 (Arduino, Teensy 4.0)"
//#define DEBUG_PIN_OUT 2     // Pin 2, output pin, software debugging use only
#define CAM_TRIG_OUT 9      // Pin 9, output pin, Trigger Signal to camera EXT TRIGGER input to start capturing image
#define CAM_TRIG_READY 10   // Pin 10, input Pin, Camera TRIGGER_READY signal from camera
#define GATE_A LED_BUILTIN  // Pin 13, digital output, ch-A MOSFET GATE, active HIGH  (used by on-board LED as well)
#define GATE_B 14           // Pin 14, digital output, ch-B MOSFET GATE, active HIGH
#define TRIG_RDY_AFTER_EXPO 15000  // Processing Time (in us) of camera after exposure, ie CAM_TRIG_READY goes HIGH again after Exposure ends. 10ms - 14ms
#define CAM_TRIG_READY_WAIT_TIMEOUT 15000000 // Start of test, 15s wait time for CAM_TRIG_READY to go HIGH

/* Time intervals definition:
      <----------------- Cycle Duration (Cycle m) ---------------------><-- (Cycle m+1) ....
         Frame n                   Frame (n+1)
      +----------+             +----------------+                      +-
      |    t1    |      t2     |       t3       |          t4          |
      |    xx ms |      xx ms  |       xx ms    |          xx ms       |
 _____|          |_____________|                |______________________|
 <--- LED Ch-A ON ----> ^ <------ LED Ch-B ON ------->     ^      <-----
 < t5 >          < t6 > | < t7 >                < t8 >     |      < t5 >
             t_wait1 ---+                        t_wait2---+
Users specify timing in ms, but timing variables (unsigned long) are in us for better timing control.
unsigned long is 32-bit for Teency ==> max time = 4,294,967,295us = 71.5min
*/
volatile unsigned long t1 = 10000;           // 10ms
volatile unsigned long t2 = 15000;           // 15ms
volatile unsigned long t3 = 40000;           // 40ms
volatile unsigned long t4 = 100000;          // 100ms
volatile unsigned long t5 = 15;              // 0ms;  put t5=15us for t5=0ms setting to cater for MCU response time
volatile unsigned long t6 = 0;               // 0ms;  put t6= 0us for t6=0ms setting
volatile unsigned long t7 = 15;              // 0ms;  put t7=15us for t7=0ms setting to cater for MCU response time
volatile unsigned long t8 = 0;               // 0ms;  put t8= 0us for t8=0ms setting
volatile unsigned long ts = 10000;           // 10ms; wait time for end of TRIG_RDY signal before switch off the LED
volatile unsigned long t_cycle = t1 + t2 + t3 + t4;
volatile long t_wait1 = t2 - t6 - t7;
volatile long t_wait2 = t4 - t8 - t5;
volatile unsigned long cycle_Total = 1000;               // Total No of loop to run  under start_test_Exposure_LED_timed().  One loop could be 1 (if t1=0 or t3=0) or 2 images taken.
unsigned long cycleNo = 0;
unsigned long previousMicros = 0;               // variable to handle overflow of micros() function.
volatile bool ch = false;                       // Toggle between ch-A (false) and ch-B (true)
bool streamingMode = false;                     // streaming mode status: 0=off, 1: on
char msgbuf[4096];                              // line buffer to print messages
IntervalTimer pulseTimer;                       // use of timer to detect pulse width
IntervalTimer cam_ExpoTimer;                    // use of timer to time if camera starts/stops exposure
volatile unsigned long pulseStartTime = 0;      // start time of falling edge, in micro seconds

// Refer 'void init_for_new_test()' for refreshed values of following variables before new test
volatile bool on_gr_red[] = {0, 0};    // Enable LEDs {Ch-A, Ch-B}. 0=Disable, 1=Enable
volatile long frameNo = 0;             // count of valid pulse on CAM_TRIG_READY pin, calculating successful captured frame by camera
unsigned long trig_rdy_width_min[] = {0, 0};  // Minimum Pulse width (us) on CAM_TRIG_READY pin for Ch-A and Ch-B
unsigned long trig_rdy_width_max[] = {0, 0};  // Maximum Pulse width (us) on CAM_TRIG_READY pin for Ch-A and Ch-B
volatile bool measuringTrigRdy = false;       // refer handleCamTrigReadyFalling() on definition of this flag
bool strmTrigRdyFalling = false;              // Streaming Mode, flag for CAM_TRIG_READY signal falling edge successful detection
// end of 'void init_for_new_test()' variable list


// Extract and print hours, minutes, and seconds in hhmmss.xxx
void print_hhmmss(unsigned long duration_ms, unsigned long totalLoops) {
    double total_duration_s = duration_ms * totalLoops / 1000;
    int hours = (int)(total_duration_s / 3600);
    int minutes = (int)((total_duration_s - (hours * 3600)) / 60);
    double seconds = ( (duration_ms * totalLoops) % 60000) / 1000.0;
    sprintf(msgbuf, "%02d:%02d:%05.3f s", hours, minutes, seconds);
    Serial.print(msgbuf);
}

/* 
CAM_TRIG_READY signal from Camera vs 'mmeasuringTrigRdy' flag and 'frameNo' count.
      |  frameNo = n   |         frameNo = n+1         |
------+                +-------+                       +---------------
      |measuringTrigRdy|       |                       |
=false|   =true        | =false|        =true          |  =false
      |________________|       |_______________________|
              --->~10ms<---                   --->~10ms<---

TRIG_OUT signal to EXT TRIGGER input of camera
      +----------+             +----------------+
      |          |             |                |
      |    t1    |      t2     |       t3       |          t4          
 _____|          |_____________|                |______________________

Definition: Presence of rising edge of CAM_TRIG_READY after TRIG_OUT is defined as camera has responded and completed one frame of image capture.
  . measuringTrigRdy=true starts at falling edge of TRIGGER READY signal   ==> Camera sets TRIGGER READY signal low.
  . measuringTrigRdy=true means TRIG_OUT signal to camera is active.  Camera has been triggered to take image.
  . measuringTrigRdy=true ends ~10ms (10ms is camera processing time) after falling edge of TRIG_OUT signal,
                       ie ends ~10ms after end of exposure.                ==> Camera sets TRIGGER READY signal high
  . absence of this rising edge within trig_rdy_width_min and trig_rdy_width_max means camera is not responding to TRIG_OUT
*/

// ISR to handle the falling edge of CAM_TRIG_READYtrig_rdy_width_min
void handleCamTrigReadyFalling() {
  if (!measuringTrigRdy) {
    measuringTrigRdy = true;
    pulseStartTime = micros();
    attachInterrupt(digitalPinToInterrupt(CAM_TRIG_READY), handleCamTrigReadyRising, RISING);
  }
}

// ISR to handle the rising edge of CAM_TRIG_READY
void handleCamTrigReadyRising() {
  unsigned long pulseEndTime = micros();
  unsigned long pulseDuration = pulseEndTime - pulseStartTime;
  // Detect camera has captured the frame, ie if the pulse length is within trig_rdy_width_min and trig_rdy_width_max
  if (pulseDuration >= trig_rdy_width_min[ch] && pulseDuration <= trig_rdy_width_max[ch]) {
      frameNo++;
  } else {  // Show abnormaly timing only if test is running.
      Serial.print("\nAlert.  End of Camera Trig Ready signal is arriving late.\n");
      sprintf(msgbuf, "Pulse Duration, min, max : %lu, %lu, %lu\n", pulseDuration, trig_rdy_width_min[ch], trig_rdy_width_max[ch]);
      Serial.print(msgbuf);
  }
  // Reset for the next pulse measurement;  Indication of camera has captured this frame
  measuringTrigRdy = false;
  attachInterrupt(digitalPinToInterrupt(CAM_TRIG_READY), handleCamTrigReadyFalling, FALLING);
}

void handleCamTrigReadyFalling_Streaming() {
  strmTrigRdyFalling = true;
  frameNo++;
  on_gr_red[ch] = 1;

}

void gateA_on() {
    digitalWrite(GATE_B, LOW);   // guarantee B is OFF first
    digitalWrite(GATE_A, HIGH);
}

void gateA_off() {
    digitalWrite(GATE_A, LOW);
}

void gateB_on() {
    digitalWrite(GATE_A, LOW);   // guarantee A is OFF first
    digitalWrite(GATE_B, HIGH);
}

void gateB_off() {
    digitalWrite(GATE_B, LOW);
}

void saveToEEPROM(unsigned int memblock) {
  int address = memblock * 100;

  unsigned long temp_t1, temp_t2, temp_t3, temp_t4, temp_t5;
  unsigned long temp_t6, temp_t7, temp_t8, temp_ts, temp_cycle_Total;
  bool tempCh;

  noInterrupts();
  temp_t1 = t1;
  temp_t2 = t2;
  temp_t3 = t3;
  temp_t4 = t4;
  temp_t5 = t5;
  temp_t6 = t6;
  temp_t7 = t7;
  temp_t8 = t8;
  temp_ts = ts;
  temp_cycle_Total = cycle_Total;
  tempCh = ch;
  interrupts();

  EEPROM.put(address, temp_t1); address += sizeof(temp_t1);
  EEPROM.put(address, temp_t2); address += sizeof(temp_t2);
  EEPROM.put(address, temp_t3); address += sizeof(temp_t3);
  EEPROM.put(address, temp_t4); address += sizeof(temp_t4);
  EEPROM.put(address, temp_t5); address += sizeof(temp_t5);
  EEPROM.put(address, temp_t6); address += sizeof(temp_t6);
  EEPROM.put(address, temp_t7); address += sizeof(temp_t7);
  EEPROM.put(address, temp_t8); address += sizeof(temp_t8);
  EEPROM.put(address, temp_ts); address += sizeof(temp_ts);
  EEPROM.put(address, temp_cycle_Total); address += sizeof(temp_cycle_Total);
  EEPROM.put(address, tempCh); address += sizeof(tempCh);
}
void readFromEEPROM(unsigned int memblock) {
  int address = memblock * 100;

  unsigned long temp_t1, temp_t2, temp_t3, temp_t4, temp_t5;
  unsigned long temp_t6, temp_t7, temp_t8, temp_ts, temp_cycle_Total;
  bool tempCh;

  EEPROM.get(address, temp_t1);           address += sizeof(temp_t1);
  EEPROM.get(address, temp_t2);           address += sizeof(temp_t2);
  EEPROM.get(address, temp_t3);           address += sizeof(temp_t3);
  EEPROM.get(address, temp_t4);           address += sizeof(temp_t4);
  EEPROM.get(address, temp_t5);           address += sizeof(temp_t5);
  EEPROM.get(address, temp_t6);           address += sizeof(temp_t6);
  EEPROM.get(address, temp_t7);           address += sizeof(temp_t7);
  EEPROM.get(address, temp_t8);           address += sizeof(temp_t8);
  EEPROM.get(address, temp_ts);           address += sizeof(temp_ts);
  EEPROM.get(address, temp_cycle_Total);  address += sizeof(temp_cycle_Total);
  EEPROM.get(address, tempCh);            address += sizeof(tempCh);

  noInterrupts();
  t1 = temp_t1;
  t2 = temp_t2;
  t3 = temp_t3;
  t4 = temp_t4;
  t5 = temp_t5;
  t6 = temp_t6;
  t7 = temp_t7;
  t8 = temp_t8;
  ts = temp_ts;
  cycle_Total = temp_cycle_Total;
  ch = tempCh;
  interrupts();
}

// Function to read an unsigned long (32-bit) value from EEPROM
unsigned long readUnsignedLong(unsigned int address) {
  unsigned long value = 0;
  for (int i = 0; i < 4; i++) {
    value |= ((unsigned long)EEPROM.read(address + i)) << (8 * i);
  }
  return value;
}


// Print current status;  '?' command
void print_currentStatus() {
    sprintf(msgbuf, "\n\
Current Status: (type 'help' to list available commands)\n\
      Active Channel : %s\n\
      Channel A      : %s\n\
      Channel B      : %s\n",\
      ch ? "ch B" : "ch A",\
      on_gr_red[0] ? "on" : "off",\
      on_gr_red[1] ? "on" : "off");
    Serial.print(msgbuf);
    show_timing_setting();
}

// Reset/Re-initialised to start run a new test
void init_for_new_test() {
  on_gr_red[0] = 0;
  on_gr_red[1] = 0;
  gateA_off();
  gateB_off();
  frameNo = 0;
  trig_rdy_width_min[0] = t1;                                 // Minimum Pulse width (us) on CAM_TRIG_READY pin for Ch-A
  trig_rdy_width_max[0] = t1 + TRIG_RDY_AFTER_EXPO + 2000;    // Maximum Pulse width (us) on CAM_TRIG_READY pin for Ch-A
  trig_rdy_width_min[1] = t3;                                 // Minimum Pulse width (us) on CAM_TRIG_READY pin for Ch-B
  trig_rdy_width_max[1] = t3 + TRIG_RDY_AFTER_EXPO + 2000;    // Maximum Pulse width (us) on CAM_TRIG_READY pin for Ch-B
  measuringTrigRdy = false;
  strmTrigRdyFalling = false;
}


void setup() {
  // Set UART baudrate to 115200
  Serial.begin(115200);

  // Configure GATE_A pin as output
  pinMode(GATE_A, OUTPUT);  
  digitalWrite(GATE_A, LOW);    // LED OFF initially

  // Configure GATE_B pin as output
  pinMode(GATE_B, OUTPUT); 
  digitalWrite(GATE_B, LOW);    // LED OFF initially

  // Configure CAM_TRIG_READY pin as input with pull-up resistor, and attach falling edge to ISR handleCamTrigReadyFalling() when required
  pinMode(CAM_TRIG_READY, INPUT_PULLUP);
  
  // Trigger Out signal to camera, active HIGH
  pinMode(CAM_TRIG_OUT, OUTPUT);
  digitalWrite(CAM_TRIG_OUT, LOW);

  // Initialise a bunch of variables
  init_for_new_test();

  // Load default timing from EEPROM
  readFromEEPROM(0);
  
  // Say Hello to the world
  sprintf(msgbuf, "\n%s\n", DEVICE_NAME);
  Serial.print(msgbuf);
}


// Streaming mode - ISR will set strmTrigRdyFalling (to true) on falling edge detection of CAM_TRIG_READY.
// As long as strmTrigRdyFalling continues to be set, the timer is refreshed every ts+2550 us and LED is kept on, frameNo countinng continues.  
// If the timer expires, the LED is off and Total frameNo is printed out and the loop is auto-reinitialised and standby for next new test.

// Time out on presence of CAM_TRIG_READY signal (EXPOSURE), turn off LED
void timerCallback() {
  printf("\nEnd of streaming, LED turned OFF\n");
  on_gr_red[ch] = 0;
  cam_ExpoTimer.end();
  frameNo--;  // Last falling edge of TRIG_OUT_READY is end of streaming, not new frame count.
  if (frameNo == 0) {
    Serial.print("  Time out waiting for response from Camera.\n");
    Serial.print("  Likely exposure timing (ts) in microcontroller does not match with MicroManager setting.  Use 'ts <value>' command to set correctly the exposure timing\n");
  }
  sprintf(msgbuf, "LED ON time Total Frames: %ld (Note: Different from the total images saved by the camera)\n", frameNo);
  Serial.print(msgbuf);

  // Reset back the frameNo, and standby for next streaming cycles
  frameNo = 0;  // Reset LED On time Total Frames
  Serial.print("\n\n\nStandby to turn ON LED when camera runs...\n");
  Serial.print("       0: ");
}

// "stm"  Continuous streaming (Camera exposure control is set by MicroManager/Camera)
// CAM_TRIG_READY pin is used to detect camera image capturing activity to turn ON/OFF the LED.
// Camera trigger source is configured as internal trigger in this mode, with it's output pin configured as "EXPOSURE" functionality

void set_streaming_mode() {
  // initialise all variables
  init_for_new_test();

  // Attached ISR - CAM_TRIG_READY pin (EXPOSURE signal)
  attachInterrupt(digitalPinToInterrupt(CAM_TRIG_READY), handleCamTrigReadyFalling_Streaming, FALLING);

  // Status for users attention
  Serial.print("\nContinuous Streaming Mode\n");
  Serial.print("(Use 'stm off' command to stop auto-LED operation, or stop the streaming mode from MicroManager)\n");
  sprintf(msgbuf, "  Current active channel : ch %c\n", ch ? 'B' : 'A');
  Serial.print(msgbuf);
  sprintf(msgbuf, "      Exposure time (ts) : %lu ms\n", ts/1000);
  Serial.print(msgbuf);
  Serial.print("\nStandby to turn ON LED when camera runs...\n");
  Serial.print("       0: ");
}
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
void loop() {
  listen_command(); // Listen and process remote control command, if any

  // only the selected channel can turn ON, and the other channel is forced LOW.
  digitalWrite(GATE_A, (ch == 0 && on_gr_red[0]) ? HIGH : LOW);
  digitalWrite(GATE_B, (ch == 1 && on_gr_red[1]) ? HIGH : LOW);

// Streaming mode - ISR will set strmTrigRdyFalling (to true) on falling edge detection of CAM_TRIG_READY.
// As long as strmTrigRdyFalling continues to be set, the timer is refreshed every ts+100000 us and LED is kept on, frameNo countinng continues.  
// If the timer expires, the LED is off and Total frameNo is printed out and the loop is auto-reinitialised and standby for next new test.
  if (strmTrigRdyFalling) {    // print out indication successful frame detected, and which LED is used
    if (frameNo %100 == 0) {  
      sprintf(msgbuf,"\n%8ld: ", frameNo);
      Serial.print(msgbuf);
    } else {
      Serial.print((ch) ? "B" : "A");
    }
    strmTrigRdyFalling = false;
    cam_ExpoTimer.begin(timerCallback, ts + 100000); // re-initialise timer for next frame
  }
}

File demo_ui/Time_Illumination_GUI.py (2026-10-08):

# Tk/ttk serial controller for Timed_Cam_Trig_LED_Control.ino.
#  python -m pip install pyserial


from __future__ import annotations

import os
import queue
import re
import threading
from datetime import datetime
from pathlib import Path
import tkinter as tk
from tkinter import messagebox, scrolledtext, ttk

try:
    import serial
    from serial.tools import list_ports
except ImportError:  # Keep the module importable so a useful GUI error can be shown.
    serial = None
    list_ports = None


BAUD_RATE = 115200
POLL_INTERVAL_MS = 50


class TimeIlluminationApp(tk.Tk):
    """Thread-safe ttk front end for the Teensy serial command interface."""

    def __init__(self) -> None:
        super().__init__()
        self.title("NOBIC/SCELSE/NTU - Time Illumination Controller")
        self.geometry("850x1100")
        self.minsize(850, 700)

        self.serial_port = None
        self.reader_thread: threading.Thread | None = None
        self.stop_reader = threading.Event()
        self.rx_queue: queue.Queue[tuple[int, str, str]] = queue.Queue()
        self.cpu_parse_buffer = ""
        self.cpu_stream_tail = ""
        self.write_lock = threading.Lock()
        self.connected = False
        self.connection_generation = 0

        self.port_var = tk.StringVar()
        self.connection_var = tk.StringVar(value="Disconnected")
        self.channel_var = tk.StringVar(value="A")
        self.led_states = {"A": "OFF", "B": "OFF"}
        self.led_status_var = tk.StringVar(value="")
        self.mode_var = tk.StringVar(value="")
        self.run_status_var = tk.StringVar(value="")
        self.test_running = False
        self.camera_wait_seconds = 0
        self.camera_countdown_after_id: str | None = None
        self.command_var = tk.StringVar()
        self.diagram_var = tk.StringVar()
        self.timing_vars = {
            name: tk.StringVar(value="—") for name in [
                "t1", "t2", "t3", "t4", "t5", "t6", "t7", "t8"
            ]
        }
        self.ts_var = tk.StringVar(value="—")
        self.cycles_var = tk.StringVar(value="—")
        self.confirmed_values = {
            name: "—" for name in [
                "t1", "t2", "t3", "t4", "t5", "t6", "t7", "t8", "ts", "cycles"
            ]
        }
        self.setting_retry_required: set[str] = set()
        self.pending_setting_group: str | None = None
        self.diagram_values = {
            name: "—" for name in ["t1", "t2", "t3", "t4", "t5", "t6", "t7", "t8"]
        }

        self.connected_widgets: list[tk.Widget] = []
        self._build_ui()
        for name, variable in self.timing_vars.items():
            variable.trace_add("write", lambda *_args, n=name: self._on_setting_changed(n))
        self.ts_var.trace_add("write", lambda *_args: self._on_setting_changed("ts"))
        self.cycles_var.trace_add(
            "write", lambda *_args: self._on_setting_changed("cycles")
        )
        self.mode_var.trace_add(
            "write", lambda *_args: self._on_mode_changed()
        )
        self._set_connected_state(False)
        self.refresh_ports()
        self._update_diagram()
        self._show_idle_status()
        self.after(POLL_INTERVAL_MS, self._process_rx_queue)
        self.protocol("WM_DELETE_WINDOW", self._on_close)

        if serial is None:
            self.after(
                100,
                lambda: messagebox.showerror(
                    "Missing dependency",
                    "PySerial is required. Install it with:\n\npython -m pip install pyserial",
                ),
            )

    def _build_ui(self) -> None:
        self.columnconfigure(0, weight=1)
        self.rowconfigure(3, weight=1)

        connection = ttk.LabelFrame(self, text="Serial Connection", padding=10)
        connection.grid(row=0, column=0, sticky="ew", padx=10, pady=(10, 5))
        connection.columnconfigure(5, weight=1)
        ttk.Label(connection, text="COM port:").grid(row=0, column=0, padx=(0, 6))
        self.port_combo = ttk.Combobox(
            connection, textvariable=self.port_var, state="readonly", width=10
        )
        self.port_combo.grid(row=0, column=1, padx=(0, 6))
        self.refresh_button = ttk.Button(
            connection, text="↻", width=3, command=self.refresh_ports
        )
        self.refresh_button.grid(row=0, column=2, padx=(0, 6))
        self.connect_button = ttk.Button(
            connection, text="Connect", width=14, command=self.toggle_connection
        )
        self.connect_button.grid(row=0, column=3, padx=(0, 4))
        ttk.Separator(connection, orient="vertical").grid(
            row=0, column=4, sticky="ns", padx=(4, 4)
        )
        ttk.Label(
            connection,
            textvariable=self.connection_var,
            anchor="w",
            foreground="green",
        ).grid(
            row=0, column=5, sticky="w"
        )
        setup_button = ttk.Button(
            connection,
            text="Connection & Micro-Manager Setup",
            width=35,
            command=self._open_setup_pdf,
        )
        setup_button.grid(row=0, column=6, padx=(8, 6))
        ttk.Button(connection, text="Exit", width=8, command=self._on_close).grid(
            row=0, column=7
        )

        diagram_frame = ttk.LabelFrame(self, text="Timing Configuration", padding=8)
        diagram_frame.grid(row=1, column=0, sticky="ew", padx=5, pady=5)
        diagram_frame.columnconfigure(0, minsize=220)
        diagram_frame.columnconfigure(1, weight=1)
        ttk.Label(
            diagram_frame,
            textvariable=self.diagram_var,
            font=("Consolas", 10),
            anchor="center",
            justify="left",
        ).grid(row=0, column=1, sticky="ew")
        run_controls = ttk.Frame(diagram_frame)
        run_controls.grid(row=0, column=0, padx=(2, 2), pady=(15, 0))
        run_controls.columnconfigure(0, minsize=210)
        self.start_button = ttk.Button(
            run_controls, text="Start", width=12, command=self._toggle_test_run
        )
        # ttk.Button has no height option; ipady gives it an approximately
        # three-text-row height while preserving the native ttk appearance.
        self.start_button.grid(row=0, column=0, ipady=12, pady=(0, 1))
        ttk.Label(
            run_controls,
            textvariable=self.run_status_var,
            width=34,
            anchor="center",
            justify="center",
            foreground="green",
        ).grid(row=1, column=0)
        self.connected_widgets.append(self.start_button)

        controls = ttk.Frame(self, padding=(10, 5))
        controls.grid(row=2, column=0, sticky="ew")
        controls.columnconfigure(0, weight=1)
        controls.columnconfigure(1, weight=1)
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

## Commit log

2026-10-08 Upload Arduino firmware
    Added Arduino firmware Timed_Cam_Trig_LED_Control.ino
2026-10-08 Add 3D CAD model of enclosure
    Add 3D CAD model of enclosure
2026-10-08 Add 3D file for enclosure
    [Illum_driver_enclosure_v1b.step]
2026-10-09 Update Arduino code
2026-10-09 KiCad PCB project files
2026-10-09 KiCad schematic and PCB
    [IlluminationDriver.kicad_pcb, IlluminationDriver.kicad_sch]
2026-10-09 KiCad PCB files
2026-10-09 3D step files
    [801-87-014-10-001101.stp, DF51K-2P-2DSA(800).stp, DF51KB-2P-2DS(800).stp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]
